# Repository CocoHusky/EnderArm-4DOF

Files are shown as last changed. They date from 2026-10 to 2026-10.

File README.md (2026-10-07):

# Ender 3 → 4-DOF Robot Arm

Convert a low-cost used Creality Ender 3 or Ender 3 Pro into a programmable 4-DOF robotic arm for learning robotics, kinematics, motion control, and non-Cartesian mechanisms.

<p align="center">
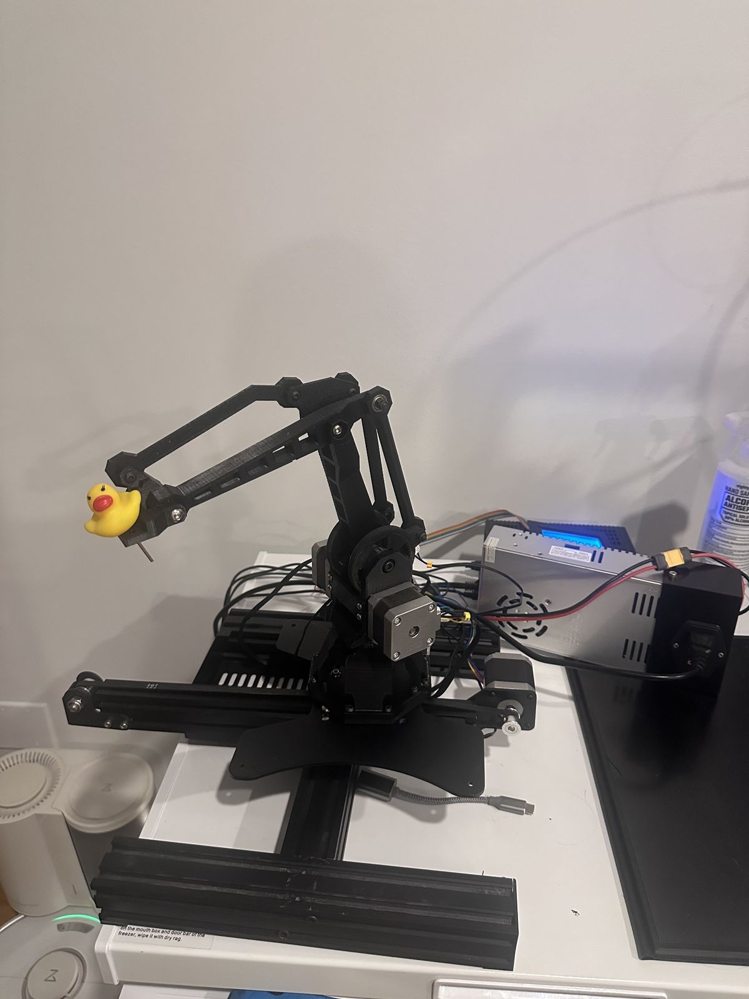
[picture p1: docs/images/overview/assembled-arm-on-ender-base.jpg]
EnderArm 4-DOF reference build mounted on the retained Ender 3 base
  
</p>

The project reuses the donor printer's frame components, stepper motors, power supply, wiring, endstops, controller board, and original linear Y-axis. The reference build was developed and tested from an Ender 3. An Ender 3 Pro can be used as well; board revisions and mounting details should always be verified before flashing firmware or assembling printed parts.

## Reference build

The photos below show the current working reference assembly and the major subsystems reused from the donor printer.

| Arm and linkage | Complete reference system |
| --- | --- |
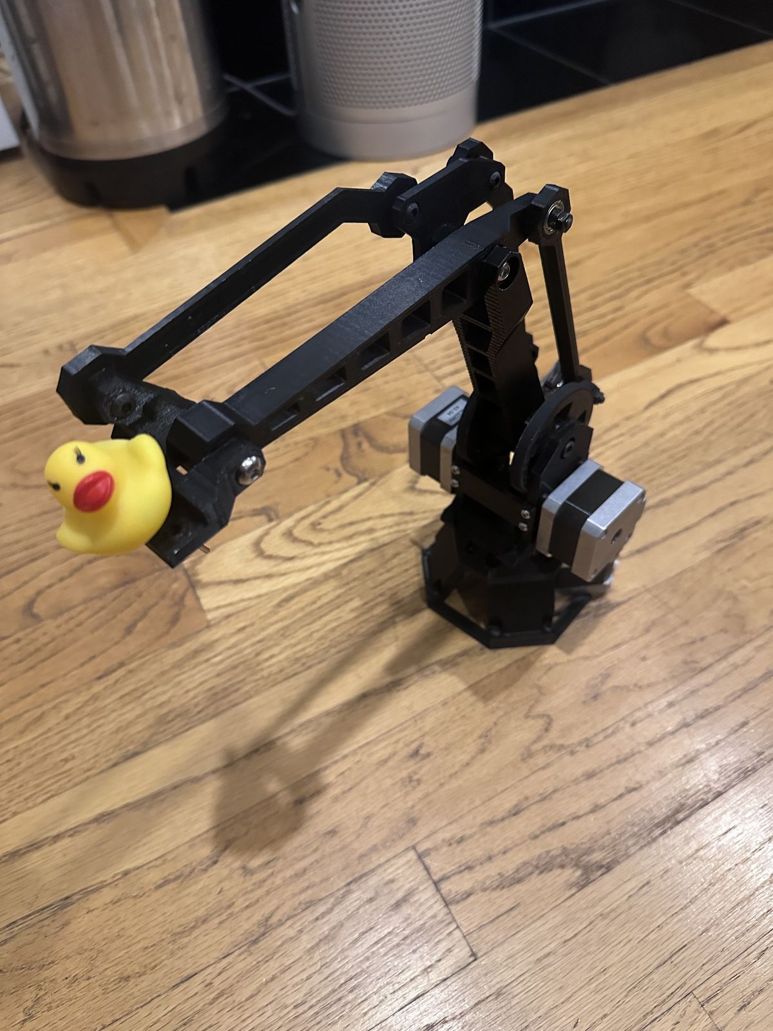
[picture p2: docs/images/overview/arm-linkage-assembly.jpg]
Standalone closed-linkage arm
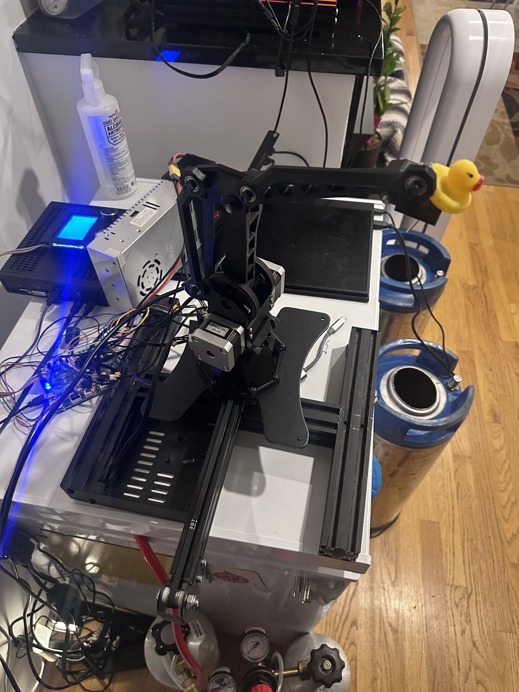
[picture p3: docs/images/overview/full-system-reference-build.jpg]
Complete EnderArm reference build
|  |  |
| **Base rotation and endstops** | **Controller and host wiring** |
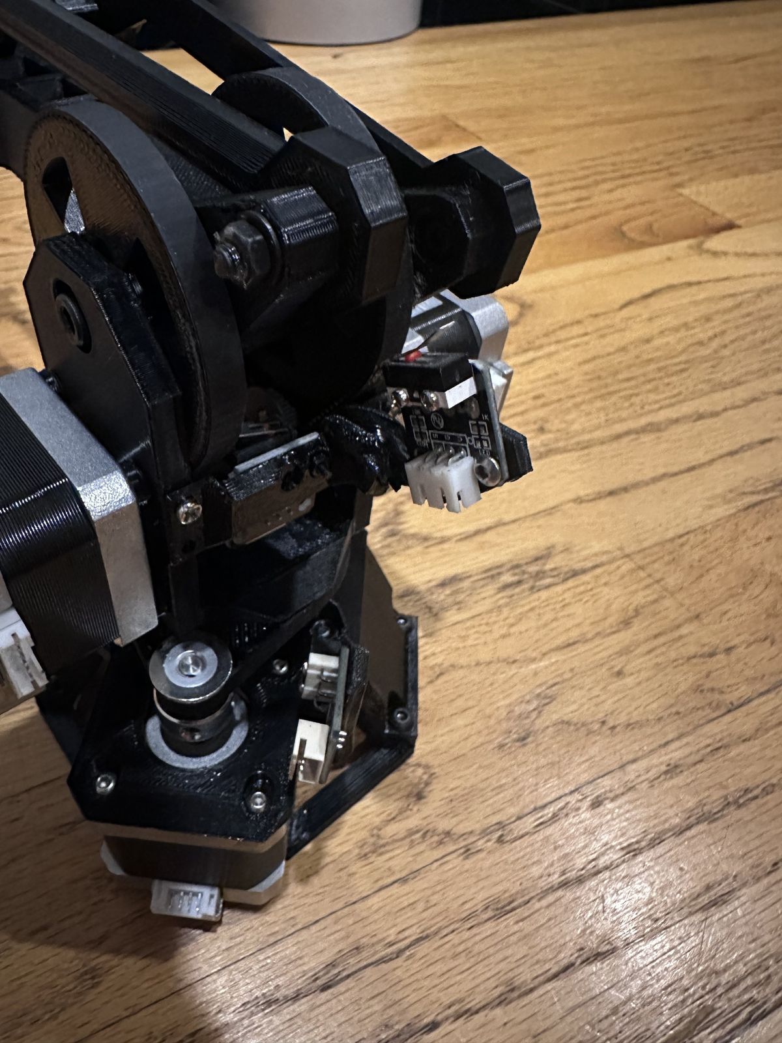
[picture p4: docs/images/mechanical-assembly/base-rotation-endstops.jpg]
Base rotation and endstop hardware
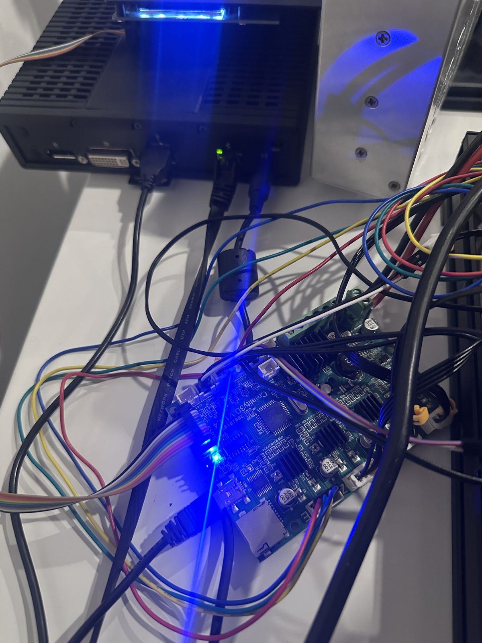
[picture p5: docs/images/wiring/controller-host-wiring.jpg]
Original Ender controller and host wiring
|  |  |

A detailed bearing and linkage close-up is available in [the mechanical assembly photos](docs/images/mechanical-assembly/linkage-bearing-detail.jpg).

## Current use: pouring beer

The current working robot is being used as a practical motion-control demo to **pour beers**. That use case exercises the same capabilities the project was built to study: repeatable homing, coordinated 4-axis motion, Cartesian targeting, smooth trajectories, and safe workspace limits.

## Why this project exists

A 3D printer is already a complete motion-control platform: stepper motors, drivers, power electronics, limit switches, belts, pulleys, a rigid frame, and a host-to-controller communication path. This project repurposes those parts into an articulated mechanism so the same hardware can be used to study:

- forward and inverse kinematics
- closed-linkage motion
- joint-space and Cartesian control
- homing and calibration
- motion planning
- workspace limits
- motor dynamics
- belt reduction
- coordinated multi-axis motion
- embedded motion control with Klipper

A used Ender 3 can often be found for roughly $30. The conversion is designed to reuse as much original hardware as possible.

## Four degrees of freedom

The arm uses four powered motions:

| DOF | Function | Donor hardware |
| --- | --- | --- |
| 1 | Linear base travel | Original Ender Y-axis carriage |
| 2 | Base rotation | Reused Ender stepper |
| 3 | Main arm joint | Reused Ender stepper, 20T-to-90T belt reduction |
| 4 | Crank/linkage joint | Reused Ender stepper, 20T-to-90T belt reduction |

The two arm-side motors drive a closed linkage rather than a conventional serial shoulder/elbow pair. The main arm is driven through the 120 mm A-C link and the second motor drives the 40 mm A-B crank. The linkage constrains the remaining arm geometry and keeps the tool structure oriented through the workspace.

## Control architecture

The reference control stack uses the original Ender controller board as the real-time motion controller running Klipper.

```text
Browser / control UI
        |
        v
Python arm controller + kinematics
        |
        v
Moonraker / Klipper host
        |
       USB
        |
        v
Original Ender controller board
        |
        v
4 stepper motors + endstops
```

The host can be any Raspberry Pi, single-board computer, mini PC, desktop, or laptop capable of running Debian/Linux, Klipper, Moonraker, and the control application.

The reference build also needed a **fourth endstop input** for the retained linear axis. On the reference 8-bit Creality board, an unused **bed-temperature / B-MOT thermistor input** was repurposed as a digital endstop input rather than adding another controller. The switch is read by Klipper as a pulled-up digital input; details are documented in the hardware/software setup.

**Minimum host requirement:** approximately **2 GB RAM and 2 GB available storage**. A dedicated host is not required if an existing Linux computer can be used.

## Additional hardware

The conversion is intended to keep the purchased hardware minimal. The reference build uses:

- GT2 timing belt, 200 mm long and 6 mm wide for the side-joint drives
- the donor X/Y stepper motors with their existing 20-tooth GT2 pulleys retained
- standard 686ZZ bearings (6 mm bore × 13 mm OD × 5 mm wide) where used by the linkage
- 6 mm precision steel balls used inside the printed bearing-shell assembly
- `686ZZ M5 Bearing Spacer.stl` adapts a standard 686ZZ for the original M5 Ender fastener while providing flange-like retention
- `Ender XY 20T Pulley Motor Spacer.stl` lets the donor X/Y steppers retain their already-installed 20T pulleys
- `6mm Ball Thrust Bearing Shell Top.stl` and `6mm Ball Thrust Bearing Shell Bottom.stl` use loose 6 mm steel balls instead of a purchased thrust bearing

The 6 mm loose balls and the 686ZZ bearings serve different functions: the loose balls run in the printed bearing shell, while the 686ZZ is used with the printed M5 bearing spacer. Exact quantities and part-by-part locations are maintained in the hardware documentation.

## Repository layout

```text
EnderArm-4DOF/
├── README.md
├── CONTRIBUTING.md
├── THIRD_PARTY.md
├── docs/
│   ├── README.md
│   ├── build/
│   ├── electronics/
│   ├── host/
│   ├── kinematics/
│   ├── calibration/
│   ├── troubleshooting/
│   └── images/
├── hardware/
│   ├── README.md
│   ├── bom/
│   ├── stl/
│   ├── step/
│   └── adapters/
├── software/
│   ├── README.md
│   ├── host/
│   ├── klipper/
│   └── tests/
└── config/
    ├── ender3/
    └── ender3-pro/
```

## Build path

1. Verify the donor printer and controller board.
2. Disassemble the X/Z gantry while retaining the Y-axis base.
3. Print the arm components and Ender-specific adapters.
4. Assemble the base rotation and closed-linkage arm.
5. Install belts, pulleys, bearings, and endstops.
6. Wire the four reused Ender steppers to the original controller.
7. Install Klipper and Moonraker on the host.
8. Install the EnderArm control software.
9. Home and calibrate each powered axis.
10. Measure the physical joint-zero offsets.
11. Validate the workspace boundary.
12. Test joint-space motion, Cartesian targets, and coordinated trajectories.

## Kinematics

The side-plane arm uses the following coordinate convention:

- origin A: the concentric side-drive pivot
- +Y: outward toward the tool
- +Z: upward
- +X: normal to the side plane
- qX: angle of the 120 mm A-C main arm
- qY: angle of the 40 mm A-B crank
- 0°: link points along +Z
- positive angle: rotation from +Z toward +Y

The main driven points are:

```text
B = (40 sin(qY), 40 cos(qY))
C = (120 sin(qX), 120 cos(qX))
```

Both side drives use a 20T motor pulley and 90T output pulley, giving a 4.5:1 reduction.

Detailed linkage geometry, forward kinematics, inverse kinematics, Cartesian-to-joint conversion, and motor-ratio math are documented in [`docs/kinematics/README.md`](docs/kinematics/README.md).

## Photos and build documentation

All build photography follows the capture plan in `docs/images/README.md`. Photos are organized by build stage so each image can be referenced directly from the corresponding assembly document.

## Third-party mechanical design

This conversion builds on an existing printable parallel-link robot-arm design. Upstream attribution and redistribution terms are documented in `THIRD_PARTY.md`.

Third-party files should only be committed to this repository when their license explicitly permits redistribution. Ender-specific adapters and modifications are maintained separately so the origin of each file remains clear.

## Project status

The mechanical conversion and arm-control workflow have been validated on the working Ender 3 reference build. Documentation, source CAD, printable files, host setup, Klipper configuration, and calibration procedures are being organized here as a reproducible build.

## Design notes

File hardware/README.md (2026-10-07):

# Hardware

This directory contains the mechanical files, Ender-specific conversion parts, and bill of materials for the Ender 3 / Ender 3 Pro to 4-DOF robot-arm conversion.

## Structure

- bom/ — donor hardware and additional parts to buy
- stl/ — arm printable files
- step/ — editable CAD exchange files
- adapters/ — Ender-specific conversion parts

Third-party printable files should retain their original attribution and license. Ender-specific parts are kept separately so it is clear which pieces belong to this conversion.

## Base arm design and assembly reference

The main arm geometry comes from the ToolKnox robotic-arm design. Use the upstream mechanical model and assembly sequence for the core printed arm parts:

- [ToolKnox robotic-arm project](https://github.com/ToolKnox/Robotic-Arm-Arduino-project)
- [Mechanical assembly guide](https://github.com/ToolKnox/Robotic-Arm-Arduino-project/blob/main/docs/assembly-guide.md)
- [Original printable model](https://www.printables.com/model/1439965-robotic-arm-arduino-project)

Follow those instructions for the **main structural arm assembly**. Then apply the Ender-specific substitutions documented below: retained Ender linear base, Ender motors/controller, printed bearing replacements, M5 bearing adapters, and motor spacers.

Do **not** follow the upstream Arduino/RAMPS electronics setup for this conversion; EnderArm reuses the Ender controller and Klipper.

## Print settings used for the conversion parts

The settings below apply to the **Ender-specific conversion parts in this repository**. For the main structural arm parts, follow the upstream ToolKnox print and assembly guidance unless intentionally changing the source design.

The Ender-specific adapter parts were dimensioned and fit-adjusted around the following print setup:

- **0.4 mm nozzle**
- **100% infill**
- **100% model scale**
- a dimensionally calibrated, high-quality FDM printer
- reference print quality comparable to a well-tuned Ender 3 Pro, Bambu Lab printer, or another printer with good dimensional accuracy

The bearing fits, shims, spacers, and motor spacing were adjusted for this printing condition. Print the conversion parts at 100% scale first.

Printer extrusion width, flow calibration, shrinkage, elephant foot, and hole compensation can still change the final fit. If a part is too tight or loose, correct printer calibration or local hole compensation rather than globally scaling the model.

## How the Ender conversion is assembled

The mechanical conversion keeps the useful motion hardware from the Ender and replaces the printer gantry with the articulated arm.

### 1. Retain the Ender linear base

Keep the original Ender Y-axis rail, carriage, belt drive, stepper, extrusion, and base frame.

This becomes the robot's **linear base axis**. The complete arm assembly rides on the original moving carriage.

### 2. Build the rotating arm base

The arm base mounts to the retained Ender carriage.

The source design uses a purchased thrust bearing at the rotating base. EnderArm replaces it with:

- [6mm Ball Thrust Bearing Shell Top.stl](adapters/6mm%20Ball%20Thrust%20Bearing%20Shell%20Top.stl)
- [6mm Ball Thrust Bearing Shell Bottom.stl](adapters/6mm%20Ball%20Thrust%20Bearing%20Shell%20Bottom.stl)
- loose **6 mm precision steel balls**

The two printed shells form the bearing race and the steel balls run between them.

### 3. Replace F624ZZ bearings with standard 624ZZ bearings

Where the source arm calls for F624ZZ flanged bearings, EnderArm uses:

- standard **624ZZ bearings**
- [624ZZ Flange Shim.stl](adapters/624ZZ%20Flange%20Shim.stl)

The shim provides the required flange interface while allowing inexpensive standard 624ZZ bearings to be used.

### 4. Replace F686ZZ / M6 interfaces with standard 686ZZ + original M5 hardware

The linkage uses standard **686ZZ bearings** together with:

- [686ZZ M5 Bearing Spacer.stl](adapters/686ZZ%20M5%20Bearing%20Spacer.stl)

The 686ZZ has a 6 mm bore. The printed spacer adapts the bearing to the original Ender M5 fastener and provides the locating surface needed by the linkage.

This lets the build reuse the Ender's M5 hardware instead of requiring the source design's M6 pivot arrangement or specialty flanged bearings.

### 5. Reuse the Ender X/Y motors with their 20T pulleys still installed

The donor X/Y stepper motors already have 20-tooth GT2 pulleys on their shafts.

Use:

- [Ender XY 20T Pulley Motor Spacer.stl](adapters/Ender%20XY%2020T%20Pulley%20Motor%20Spacer.stl)

The spacer moves each motor to the correct belt plane so the original pulley can stay installed.

The two side-linkage drives use the retained **20T motor pulley → 90T driven pulley** reduction.

This gives a 4.5:1 reduction between motor-shaft angle and linkage-output angle.

### 6. Install the closed-linkage arm

Assemble the source arm geometry around the two driven 90T side joints.

The two independently powered side joints are:

- **Main-arm drive** — 120 mm A→C link
- **Crank drive** — 40 mm A→B link

The remaining pivots are passive and are constrained by the closed linkage. See [docs/kinematics/README.md](../docs/kinematics/README.md) for the complete geometry and Cartesian-to-joint math.

### 7. Install the remaining rotary drive and belts

The build uses three 200 mm × 6 mm closed-loop GT2 belts for the rotary belt-driven joints.

Two 20T pulleys are reused directly from the donor X/Y motors. The additional 20T pulley can be purchased or printed:

- [GT2 20T pulley, 5 mm bore, optimized for FDM](https://www.printables.com/model/730635-gt2-20t-pully-5mm-bore-optimized-for-fdm)

### 8. Verify the mechanism before powered motion

Before connecting powered motion:

1. Move the retained linear carriage through its full travel by hand.
2. Rotate the base and confirm the printed loose-ball bearing moves smoothly.
3. Rotate both 90T linkage outputs by hand and verify that the linkage remains on the intended assembly branch.
4. Confirm that the 624ZZ flange shims stay seated and do not bind the bearings.
5. Confirm that the 686ZZ M5 spacers locate the bearings without clamping the rotating races.
6. Check that all GT2 belts track in one plane and do not rub printed parts.
7. Verify that cables can reach the full workspace without becoming tension members.

Do not proceed to high-speed motion until every axis moves freely by hand.

## Fourth endstop using the temperature-sensor input

The 4-DOF conversion needs one more limit-switch input than the original motion layout provides.

On the **reference 8-bit Creality V1.1.4-style controller**, the unused **bed thermistor / B-MOT temperature-sensor input** was repurposed as the fourth endstop input.

Reference wiring:

```text
B-MOT / PA6  ---- switch ---- GND
```

Klipper enables the MCU pull-up, so the normally-open switch pulls the input to ground when triggered. On the reference board this was verified in Klipper: the input changed from `open` to `TRIGGERED` when the switch was held.

Important: this means that connector is no longer being used as an analog temperature input. It is intentionally reconfigured as a digital switch input for the robot.

The exact MCU pin depends on the donor-controller revision. The **PA6 mapping is for the reference 8-bit board** and should not be copied to a different Creality board revision without checking its schematic/pin map.

## Ender-specific conversion parts

| Part | Qty | Purpose |
| --- | ---: | --- |
| [624ZZ Flange Shim.stl](adapters/624ZZ%20Flange%20Shim.stl) | 6 | Allows standard 624ZZ bearings to replace F624ZZ flanged bearings |
| [6mm Ball Thrust Bearing Shell Top.stl](adapters/6mm%20Ball%20Thrust%20Bearing%20Shell%20Top.stl) | 1 | Upper race for the printed loose-ball thrust bearing |
| [6mm Ball Thrust Bearing Shell Bottom.stl](adapters/6mm%20Ball%20Thrust%20Bearing%20Shell%20Bottom.stl) | 1 | Lower race for the printed loose-ball thrust bearing |
| [686ZZ M5 Bearing Spacer.stl](adapters/686ZZ%20M5%20Bearing%20Spacer.stl) | 12 | Adapts standard 686ZZ bearings to the original Ender M5 pivot hardware |
| [Ender XY 20T Pulley Motor Spacer.stl](adapters/Ender%20XY%2020T%20Pulley%20Motor%20Spacer.stl) | 2 | Aligns donor X/Y motors while retaining their installed 20T pulleys |

For quantities of bearings, belts, fasteners, and donor parts, see the [hardware BOM](bom/).

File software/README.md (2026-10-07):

# Software

EnderArm splits high-level robot geometry from deterministic step timing.

```text
Browser UI
    |
    v
robot_mapper_klipper.py
    |
    +--> kinematics.py
    |
    v
Moonraker
    |
    v
Klipper
    |
   USB
    |
    v
original Ender controller board
```

## Host requirements

A Dell Wyse is **not required**. Use a Raspberry Pi, mini PC, old laptop, thin client, or other Debian/Linux machine.

Minimum practical target:

- **2 GB RAM**
- **2 GB available storage**
- Python 3
- USB connection to the Ender controller
- network access if the UI is opened from another device

The reference build used a used Dell Wyse only because it was cheaper than Raspberry Pi hardware at the time.

## Source files

| File | Purpose |
| --- | --- |
| [`host/kinematics.py`](host/kinematics.py) | Exact closed-linkage geometry, forward kinematics, inverse kinematics, coordinate transforms, motor/output conversion |
| [`host/robot_mapper_klipper.py`](host/robot_mapper_klipper.py) | Browser UI, workspace model, boundary checking, Moonraker communication, joint/tool commands |
| [`klipper/arm_robot.py`](klipper/arm_robot.py) | Klipper extra module for native robot-arm homing and coordinated A/B/C arm axes |
| [`tests/test_kinematics.py`](tests/test_kinematics.py) | Geometry and kinematics regression tests |

## Install Debian/Linux packages

```bash
sudo apt update
sudo apt install -y git python3
```

Install Klipper and Moonraker using their normal Linux installation process.

## Clone EnderArm

```bash
cd ~
git clone https://github.com/CocoHusky/EnderArm-4DOF.git
cd EnderArm-4DOF
```

## Install the Klipper arm module

For a normal Klipper checkout at `~/klipper`:

```bash
cp software/klipper/arm_robot.py ~/klipper/klippy/extras/arm_robot.py
```

Add this section to `printer.cfg`:

```ini
[arm_robot]
```

The current module expects these exact Klipper object names:

```ini
[manual_stepper joint_x]
# qX: main A -> C drive

[manual_stepper joint_y]
# qY: A -> B crank drive

[manual_stepper joint_z]
# base-yaw drive
```

Use the **actual step/dir/enable/endstop pins for the donor controller board**. Ender 3 and Ender 3 Pro boards exist in multiple revisions, so pin assignments from another board should not be copied blindly.

The retained Ender rail is the fourth powered coordinate. Calibrate that rail in millimetres using the real donor belt, pulley, motor, and travel.

## Start the web controller

```bash
python3 software/host/robot_mapper_klipper.py
```

The checked-in controller uses:

```text
Moonraker: http://127.0.0.1:7125
Web UI:    0.0.0.0:8765
```

Open it from another machine at:

```text
http://<linux-host-ip>:8765
```

There is no required fixed IP address.

## Inverse-kinematics path

For an arm-local Cartesian command:

```text
desired tool Y,Z
        |
        v
inverse_side()
        |
        v
qX, qY 90T output angles
        |
        v
home-offset / direction calibration
        |
        v
Klipper coordinated motion
```

`inverse_side()` uses the exact closed-linkage geometry, not a serial two-link shoulder/elbow approximation. It uses a finite-difference Jacobian with a 0.01° step, converges below 0.01 mm tool error, allows up to 80 iterations, and rejects near-singular solves when `|det(J)| < 1e-8`.

See [the full kinematics derivation](../docs/kinematics/README.md).

## Run the regression tests

```bash
cd software/host
python3 -m unittest -v ../tests/test_kinematics.py
```

The development source currently passes the geometry/kinematics regression suite before publication.

## First-power checks

Before normal operation:

1. confirm Klipper reaches `ready`
2. verify every endstop changes state correctly
3. verify motor directions at low speed
4. home one mechanism at a time
5. confirm the linkage remains on the physical Assembly-1 branch
6. verify the measured X/Y joint-space boundary
7. calibrate physical home offsets and linear-rail travel
8. check cable clearance over the full workspace

## Fourth endstop: repurposing a thermistor input

The retained linear axis requires a fourth homing/limit input.

On the reference 8-bit Creality V1.1.4-style board, the unused bed-temperature input was repurposed as a digital endstop input:

```text
B-MOT / MCU PA6 -> normally-open switch -> GND
```

The Klipper-side change is to use that MCU pin as an endstop rather than as a thermistor ADC input. For the reference board, the endstop declaration uses the internal pull-up:

```ini
# Reference 8-bit Creality board only
endstop_pin: ^PA6
```

The leading `^` enables the pull-up. With the switch open, the input remains high; closing the switch pulls PA6 to ground and Klipper reports it as triggered.

This was verified on the reference controller by watching the switch state change from `open` to `TRIGGERED`.

Do not configure the same PA6 pin simultaneously as a temperature sensor and an endstop. The temperature-sensor definition for that connector must be removed/disabled when the input is repurposed.

Different Ender controller revisions use different MCU pins, so the pin value above is specific to the reference 8-bit board.

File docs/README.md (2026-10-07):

# Documentation

The documentation is organized in the same order a new builder should follow.

## Build sequence

- `build/` — donor printer, disassembly, printed parts, and mechanical assembly
- `electronics/` — controller board, motors, endstops, power, and wiring
- `host/` — Raspberry Pi or other Debian/Linux host setup; minimum 2 GB RAM and 2 GB available storage
- `kinematics/` — linkage geometry, coordinate frames, forward and inverse kinematics
- `calibration/` — homing, zero offsets, workspace measurement, and validation
- `troubleshooting/` — mechanical, wiring, Klipper, and motion-control problems
- `images/` — required build photographs, screenshots, and validation videos

The build guide should be usable from start to finish without requiring knowledge of the development history of the project.

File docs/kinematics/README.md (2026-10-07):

# Kinematics and Cartesian-to-Motor Math

This document defines the mathematical model used by EnderArm. It intentionally separates the robot geometry from the Ender controller connector names.

All lengths are in millimetres. Public joint angles are in degrees unless otherwise noted.

## Joint map

The drawing below is generated from the same dimensions used by the kinematic model. Its illustrative pose uses `qX=+22°` and `qY=-90°` only to make the mechanism easy to read: **A→B and A→G are visibly separate**, and **F→C→H is shown as the single straight rigid member defined by the solver**. Those display angles are not home or calibration-zero values.

Exact EnderArm closed-linkage kinematics

The four powered robot coordinates are:

- `s` — linear base travel; translates the complete arm on the retained Ender rail
- `ψ` — base yaw; rotates the complete Y-Z side linkage about vertical Z
- `qX` — main-arm joint; the 90T output that directly drives A→C
- `qY` — crank joint; the 90T output that directly drives A→B

The diagram is reproducible from [`generate_kinematics_diagram.py`](generate_kinematics_diagram.py). The generator validates the fixed member lengths and F-C-H collinearity before writing the SVG.

## 1. Actuated coordinates

EnderArm has four powered coordinates:

| Symbol | Name | Meaning |
| --- | --- | --- |
| `s` | Linear base travel | Translation of the complete arm along the retained Ender linear rail |
| `ψ` | Base yaw | Rotation of the complete arm about the vertical axis |
| `qX` | Main-arm joint | Absolute angle of the 120 mm A→C driven link |
| `qY` | Crank joint | Absolute angle of the 40 mm A→B driven crank |

`qX` and `qY` are angles of the 90-tooth driven outputs, not motor-shaft angles.

The remaining labelled pivots are passive linkage points. They are determined by `qX` and `qY`.

## 2. Side-plane coordinate frame

The closed linkage is solved in the Y-Z plane.

```text
A = (Y=0, Z=0)
+Y = outward from the base toward the tool
+Z = upward

q = 0°   -> link points along +Z
q = +90° -> link points along +Y
```

Angles are therefore measured from +Z toward +Y.

The common drive origin is point A.

## 3. Link dimensions

The current physical model uses:

| Link | Length |
| --- | ---: |
| A-B | 40 mm |
| A-C | 120 mm |
| B-F | 120 mm |
| C-F | 40 mm |
| C-H | 120 mm |
| C-E / A-G | 32 mm |
| D-E | 45 mm |
| C-D / H-I | 25 mm |
| G-E / D-I | 120 mm |
| H-T | 27 mm |

The fixed support vector is

```text
G = (-26.933333, 17.279918)
```

in side-plane `(Y,Z)` coordinates.

## 4. Independent driven pivots

Let

```text
a = AB = 40
c = AC = 120
```

The crank tip B is

```text
B_y = a sin(qY)
B_z = a cos(qY)
```

or

```text
B(qY) = [40 sin(qY), 40 cos(qY)]
```

The main-arm pivot C is

```text
C_y = c sin(qX)
C_z = c cos(qX)
```

or

```text
C(qX) = [120 sin(qX), 120 cos(qX)]
```

These are the only two independent coordinates in the side linkage.

## 5. Solving the closed linkage

Point F is passive. It must simultaneously satisfy

```text
|F - B| = BF = 120
|F - C| = CF = 40
```

Therefore F is the intersection of two circles.

Define

```text
d = C - B
D = ||d||
e = d / D
```

where `e` is the unit vector from B toward C.

The distance from B to the projection of F onto the B-C line is

```text
u = (BF² - CF² + D²) / (2D)
```

The perpendicular distance from that line to F is

```text
h = sqrt(BF² - u²)
```

A perpendicular unit vector in the Y-Z plane is

```text
e_perp = [-e_z, e_y]
```

The two mathematical solutions are therefore

```text
F1 = B + u e + h e_perp
F2 = B + u e - h e_perp
```

Only one corresponds to the physical assembled arm. EnderArm uses the physical Assembly-1 branch.

If the two circles do not intersect, that pair of `qX,qY` angles is not physically reachable.

## 6. Remaining passive pivots

F, C, and H are collinear. Because

```text
CF = 40
CH = 120
```

the vector from C to H is three times the vector from F to C:

```text
H = C + (CH / CF)(C - F)
H = C + 3(C - F)
```

The lower parallelogram gives

```text
E = C + G
```

The triplate gives

```text
D = E + [45, 0]
```

The upper parallelogram gives

```text
I = H + (D - C)
```

The tool point is

```text
T = H + [27, 0]
```

Thus the complete side-plane forward-kinematics function is

```text
T = f(qX, qY)
```

The tool coordinates `T_y,T_z` are fully determined by the two driven 90T joint angles.

## 7. Forward kinematics

The complete side-plane calculation is:

```text
qX, qY
  ↓
B(qY), C(qX)
  ↓
circle intersection -> F
  ↓
H = C + 3(C-F)
  ↓
T = H + [27,0]
  ↓
(T_y, T_z)
```

This is why EnderArm must not be modeled as an ordinary serial two-link shoulder/elbow mechanism.

## 8. Side-plane inverse kinematics

Given a desired tool position

```text
T* = [Y*, Z*]
```

we need to find

```text
q = [qX, qY]^T
```

such that

```text
f(q) = T*
```

There is no simple serial-arm elbow equation because the tool position is produced by the complete closed linkage.

The reference controller uses a Newton/Jacobian solve.

Define the error

```text
e(q) = f(q) - T*
```

or

```text
e = [
    T_y(qX,qY) - Y*
    T_z(qX,qY) - Z*
]
```

The Jacobian is

```text
J = [
    ∂T_y/∂qX   ∂T_y/∂qY
    ∂T_z/∂qX   ∂T_z/∂qY
]
```

The implementation estimates the derivatives numerically with

```text
ε = 0.01°
```

For example,

```text
∂T_y/∂qX ≈ [T_y(qX+ε,qY) - T_y(qX,qY)] / ε
∂T_z/∂qX ≈ [T_z(qX+ε,qY) - T_z(qX,qY)] / ε
```

and equivalently for `qY`.

The Newton update is

```text
q_next = q - J⁻¹ e
```

For a 2×2 Jacobian

```text
J = [a b
     c d]
```

with

```text
det(J) = ad - bc
```

the correction used by the controller is

```text
ΔqX = ( d e_y - b e_z) / det(J)
ΔqY = (-c e_y + a e_z) / det(J)

qX <- qX - ΔqX
qY <- qY - ΔqY
```

The current implementation:

- starts from the current physical joint angles
- remains on Assembly 1
- stops when tool-position error is less than 0.01 mm
- allows up to 80 iterations
- rejects the solve when `|det(J)| < 1e-8`, because the linkage is near a singularity

Using the current pose as the seed is important. The closed linkage has multiple mathematical branches, and a distant arbitrary seed can converge to the wrong assembly.

## 9. Joint coordinates and physical home

Geometric zero and physical home are different.

Geometric zero is defined by

```text
qX = 0° -> A-C points along +Z
qY = 0° -> A-B points along +Z
```

After homing, the controller maps its measured joint coordinates to geometric angles with

```text
qX = qX_home + dirX (x - x_home)
qY = qY_home + dirY (y - y_home)
```

where

- `x,y` are the measured 90T output-joint coordinates
- `x_home,y_home` are the post-home reference values
- `dirX,dirY` account for motor/wiring direction
- `qX_home,qY_home` are physical calibration offsets

The current reference values in the development model are

```text
qX_home = -70°
qY_home = -104°
```

These are calibration values for the reference arm, not universal geometric constants.

## 10. 90T output angle to motor-shaft angle

Both side drives use

```text
20T motor pulley -> 90T output pulley
```

Therefore

```text
q_output = θ_motor (20 / 90)
```

and

```text
θ_motor = q_output (90 / 20)
θ_motor = 4.5 q_output
```

For commanded changes,

```text
Δθ_motor = 4.5 Δq_output
```

Examples:

| Output-joint motion | Motor-shaft motion |
| ---: | ---: |
| 1° | 4.5° |
| 5° | 22.5° |
| 10° | 45° |
| 20° | 90° |

Stepper pulse generation should be left to Klipper using the configured motor/driver parameters rather than hard-coding a microstep count into the kinematic model.

## 11. Side-plane Cartesian command to the two arm motors

The currently implemented Cartesian move performs this sequence:

```text
desired tool Y,Z
       ↓
inverse_side(Y,Z,current qX,current qY)
       ↓
desired qX,qY
       ↓
apply physical-home offsets and direction
       ↓
desired 90T output coordinates
       ↓
Klipper coordinated motion
       ↓
20T motor pulleys drive the 90T outputs
```

In equation form,

```text
(Y*, Z*)
    -> IK
(qX*, qY*)
    -> calibration transform
(x*, y*)
    -> motion planner
motor motion
```

## 12. Extending the side-plane model to world XYZ

Base yaw rotates the side-plane radial coordinate into world X-Y.

For a side-plane tool solution

```text
T_side = [r, z]
```

and base yaw `ψ`,

```text
X = r sin(ψ)
Y = r cos(ψ)
Z = z
```

Therefore, for a world target relative to the yaw-axis origin,

```text
r = sqrt(X² + Y²)
ψ = atan2(X, Y)
z = Z
```

The side-linkage inverse problem then becomes

```text
(qX,qY) = inverse_side(r,Z)
```

and the three rotary coordinates are

```text
ψ, qX, qY
```

## 13. Adding the linear base coordinate

The retained Ender rail translates the complete yaw axis.

Let

```text
s = linear-axis position
l_hat = unit vector of the physical rail in the chosen world frame
P0 = yaw-axis origin when s = 0
```

Then the moving base origin is

```text
P_base(s) = P0 + s l_hat
```

For a requested world tool point `P*`,

```text
p = P* - P_base(s)
```

Then

```text
r = sqrt(p_x² + p_y²)
ψ = atan2(p_x, p_y)
(qX,qY) = inverse_side(r,p_z)
```

This gives

```text
P* + chosen s
    ->
p relative to moving base
    ->
ψ,r,z
    ->
qX,qY
    ->
four actuator coordinates [s,ψ,qX,qY]
```

A position-only XYZ target contains three constraints while the robot has four actuated coordinates. Therefore `s` is a redundant degree of freedom for a pure XYZ command.

A controller must choose `s` using an additional rule, for example:

- keep the current linear position when the target is reachable
- choose `s` that maximizes distance from the side-linkage workspace boundary
- minimize total joint motion
- minimize motor effort
- prefer the center of linear travel

Once `s` is chosen, the remaining inverse mapping is deterministic for the selected physical linkage branch.

## 14. Complete mathematical control chain

```text
Desired world tool point P*
        +
linear-axis policy
        ↓
choose s
        ↓
P_base(s) = P0 + s l_hat
        ↓
p = P* - P_base(s)
        ↓
ψ = atan2(p_x,p_y)
r = sqrt(p_x²+p_y²)
z = p_z
        ↓
closed-linkage IK
        ↓
qX, qY
        ↓
home-offset / direction calibration
        ↓
90T output coordinates
        ↓
20T:90T ratio
        ↓
motor-shaft motion
        ↓
Klipper trajectory generation
```

The kinematic layer should produce physical actuator coordinates. Klipper should remain responsible for converting those coordinates into timed step pulses.

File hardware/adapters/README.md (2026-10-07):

# Ender-specific adapters

These parts were created for the EnderArm conversion so the build can reuse original Ender hardware and lower-cost commodity bearings.

## Print settings

The adapter geometry and fit were tuned around:

- **0.4 mm nozzle**
- **100% infill**
- **100% model scale**
- a dimensionally calibrated FDM printer with good dimensional accuracy

A well-tuned Ender 3 Pro, Bambu Lab printer, or another high-quality printer should be an appropriate starting point.

The bearing seats, shims, M5 interface, and motor spacing include fit adjustments based on these settings. Printer calibration still matters: flow, shrinkage, elephant foot, and hole compensation can change a nominally identical print.

## 624ZZ flange shim

[624ZZ Flange Shim.stl](624ZZ%20Flange%20Shim.stl) allows a standard 624ZZ bearing to be used where the source design calls for an F624ZZ flanged bearing.

Use one shim with each 624ZZ bearing.

## 6 mm ball thrust-bearing shell

[6mm Ball Thrust Bearing Shell Top.stl](6mm%20Ball%20Thrust%20Bearing%20Shell%20Top.stl) and [6mm Ball Thrust Bearing Shell Bottom.stl](6mm%20Ball%20Thrust%20Bearing%20Shell%20Bottom.stl) form the printed thrust-bearing race.

Fill the race with 6 mm precision steel balls during assembly. This replaces the purchased thrust-bearing assembly used by the source robot design.

## 686ZZ M5 bearing spacer

[686ZZ M5 Bearing Spacer.stl](686ZZ%20M5%20Bearing%20Spacer.stl) is used with a standard 686ZZ bearing.

The 686ZZ has a 6 mm bore. The spacer creates the M5-compatible pivot interface required to reuse the original Ender fastener and provides the locating surface needed by the linkage.

## Ender XY 20T pulley motor spacer

[Ender XY 20T Pulley Motor Spacer.stl](Ender%20XY%2020T%20Pulley%20Motor%20Spacer.stl) positions the donor X/Y stepper motors correctly for the arm belt drives.

It is specifically designed so the original 20-tooth GT2 pulley can remain installed on the motor shaft.

## Files

- 624ZZ Flange Shim.stl
- 6mm Ball Thrust Bearing Shell Top.stl
- 6mm Ball Thrust Bearing Shell Bottom.stl
- 686ZZ M5 Bearing Spacer.stl
- Ender XY 20T Pulley Motor Spacer.stl

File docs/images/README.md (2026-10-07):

# Build photography

Use this directory for the photographs and screenshots referenced by the build documentation.

Photographs should be clear engineering documentation rather than decorative images. Use a clean background, even lighting, and enough resolution to show hardware details. Keep the same arm orientation between related photos when possible.

## Current reference photos

These cleaned reference-build photographs are already included in the repository:

| File | Use |
| --- | --- |
| `overview/assembled-arm-on-ender-base.jpg` | Arm mounted on the retained Ender base |
| `overview/arm-linkage-assembly.jpg` | Standalone closed-linkage arm assembly |
| `overview/full-system-reference-build.jpg` | Complete working system and retained linear axis |
| `mechanical-assembly/linkage-bearing-detail.jpg` | Linkage bearing and fastener detail |
| `mechanical-assembly/base-rotation-endstops.jpg` | Base rotation and endstop arrangement |
| `wiring/controller-host-wiring.jpg` | Original Ender controller and host connection |

The repository copies are re-encoded JPEGs with camera metadata removed.

## File format

- Photos: JPG
- Diagrams and screenshots: PNG or SVG
- Video clips: MP4
- Short motion previews: GIF only when a static image cannot explain the action
- Use lowercase filenames with hyphens
- Do not include camera-generated names such as `IMG_4821.jpg`

## overview

These are the main project images.

| File | Shot |
| --- | --- |
| `overview/hero-assembled-arm.jpg` | Finished arm, front three-quarter view, neutral pose |
| `overview/hero-side-view.jpg` | Finished arm, exact side view showing the closed linkage |
| `overview/ender3-before.jpg` | Complete donor Ender 3 before disassembly |
| `overview/ender3-to-arm.jpg` | Donor printer and finished arm shown together or as a clean before/after pair |
| `overview/arm-in-motion.jpg` | Arm in a useful extended pose |
| `overview/workspace-poses.jpg` | Three or more representative poses showing the available workspace |

The main README should use `hero-assembled-arm.jpg` once it exists.

## donor-printer

Document exactly what the builder starts with.

| File | Shot |
| --- | --- |
| `donor-printer/ender3-front.jpg` | Full Ender 3 from the front |
| `donor-printer/ender3-pro-front.jpg` | Ender 3 Pro example, if available |
| `donor-printer/controller-board.jpg` | Controller board with board revision readable |
| `donor-printer/controller-connectors.jpg` | Motor, endstop, power, and USB connectors visible |
| `donor-printer/donor-motors.jpg` | Four donor stepper motors laid out and labeled by original axis |
| `donor-printer/reused-hardware.jpg` | Screws, T-nuts, endstops, belts, pulleys, wiring, and other reused hardware laid out |
| `donor-printer/y-axis-base.jpg` | Original Y-axis base assembly that remains in the robot |

## disassembly

Take each photo before removing the next major assembly.

| File | Shot |
| --- | --- |
| `disassembly/stock-printer.jpg` | Printer before disassembly |
| `disassembly/remove-top-crossbar.jpg` | Top crossbar fasteners and removal |
| `disassembly/remove-x-gantry.jpg` | X gantry before and during removal |
| `disassembly/remove-z-extrusions.jpg` | Vertical extrusions and mounting screws |
| `disassembly/remove-unused-components.jpg` | Extruder/hotend and printer-only components being removed |
| `disassembly/retained-base.jpg` | Final retained Ender base with Y-axis carriage |
| `disassembly/retained-parts-layout.jpg` | Every donor part used by the arm laid out and labeled |
| `disassembly/unused-parts-layout.jpg` | Major donor parts not required for the conversion |

## printed-parts

These images let a builder identify every printed part before assembly.

| File | Shot |
| --- | --- |
| `printed-parts/all-parts-labeled.jpg` | Complete printed-parts set with labels matching STL filenames |
| `printed-parts/print-orientation-arm-parts.jpg` | Recommended print orientation for the major linkage parts |
| `printed-parts/print-orientation-adapters.jpg` | Recommended orientation for the Ender-specific adapters |
| `printed-parts/m5-bearing-spacer.jpg` | M5-to-bearing spacer alone, close and in focus |
| `printed-parts/m5-bearing-spacer-installed.jpg` | Spacer installed in the bearing interface with an original M5 screw |
| `printed-parts/printed-20t-pulley.jpg` | Optional printed 20T pulley, if used |
| `printed-parts/90t-output-pulley.jpg` | 90T output pulley/gear used by the side joints |

## hardware

Show every non-printed purchased component at a scale that makes identification easy.

| File | Shot |
| --- | --- |
| `hardware/gt2-belt.jpg` | GT2 belt with width and length reference |
| `hardware/20t-pulley.jpg` | 20T GT2 motor pulley |
| `hardware/686zz-bearing.jpg` | 686ZZ bearing with ruler/caliper or marked dimensions |
| `hardware/6mm-steel-balls.jpg` | 6 mm precision steel balls with scale reference |
| `hardware/additional-hardware-layout.jpg` | Complete purchased hardware set for one arm |

Keep the 686ZZ bearing and 6 mm steel balls as separate documented parts. The 6 mm balls belong in the printed bearing-shell assembly; the 686ZZ uses the printed M5 bearing spacer.

## mechanical-assembly

This is the most important photo set. Photograph every joint before it is hidden by the next part.

| File | Shot |
| --- | --- |
| `mechanical-assembly/linear-base.jpg` | Retained Ender Y-axis used as the linear DOF |
| `mechanical-assembly/base-rotation.jpg` | Base rotation motor, shaft/pulley, and rotating structure |
| `mechanical-assembly/side-motor-mounts.jpg` | Two side-plane motors mounted |
| `mechanical-assembly/20t-to-90t-drive.jpg` | 20T motor pulley, GT2 belt, and 90T driven pulley in one shot |
| `mechanical-assembly/main-arm-ac.jpg` | 120 mm A-C main driven arm installed |
| `mechanical-assembly/crank-ab.jpg` | 40 mm A-B crank installed |
| `mechanical-assembly/lower-linkage.jpg` | B-F/C-F lower linkage assembled |
| `mechanical-assembly/parallelogram-linkage.jpg` | Parallel-link mechanism from the side |
| `mechanical-assembly/wrist-linkage.jpg` | H-I-T tool-side linkage |
| `mechanical-assembly/bearing-stack.jpg` | Bearing, spacer, screw, printed part, and washer stack in assembly order |
| `mechanical-assembly/m5-adapter-detail.jpg` | Close-up proving the original M5 screw works with the adapter |
| `mechanical-assembly/belt-routing.jpg` | Complete belt routing for both side drives |
| `mechanical-assembly/belt-tension.jpg` | Correct belt tension and adjustment point |
| `mechanical-assembly/endstops.jpg` | Endstop locations and trigger surfaces |
| `mechanical-assembly/complete-side-view.jpg` | Finished mechanical arm in exact side view |
| `mechanical-assembly/complete-front-view.jpg` | Finished arm from the front |
| `mechanical-assembly/complete-rear-view.jpg` | Finished arm from the rear, showing wiring path |

For the exact side-view photo, position the camera normal to the linkage plane. This image will also be used to explain the kinematic points A through T.

## wiring

The reader should be able to reproduce the wiring without guessing.

| File | Shot |
| --- | --- |
| `wiring/controller-labeled.jpg` | Controller board with each used connector labeled |
| `wiring/motor-x-connection.jpg` | First linkage motor connection |
| `wiring/motor-y-connection.jpg` | Second linkage motor connection |
| `wiring/base-rotation-connection.jpg` | Base-rotation motor connection |
| `wiring/linear-axis-connection.jpg` | Retained linear-axis motor connection |
| `wiring/endstop-connections.jpg` | All endstop connections |
| `wiring/power-input.jpg` | PSU-to-controller power connection |
| `wiring/usb-host-connection.jpg` | USB connection between host and Ender controller |
| `wiring/full-wiring-overview.jpg` | Entire electrical system in one view |
| `wiring/cable-management.jpg` | Final cable routing through full arm travel |

## host

Document the reference host without making it mandatory.

| File | Shot |
| --- | --- |
| `host/dell-wyse-reference.jpg` | Dell Wyse reference host |
| `host/dell-wyse-usb-network.jpg` | USB, Ethernet, and power connections |
| `host/raspberry-pi-example.jpg` | Optional Raspberry Pi host if one is tested |
| `host/laptop-usb-example.jpg` | Computer-hosted setup over USB |

## software

Use screenshots rather than camera photos.

| File | Shot |
| --- | --- |
| `software/klipper-ready.png` | Klipper/Moonraker showing the controller ready |
| `software/control-ui-home.png` | Main arm-control page after homing |
| `software/live-arm-view.png` | Live kinematic arm visualization |
| `software/joint-controls.png` | Joint-space controls |
| `software/cartesian-target.png` | Cartesian target controls |
| `software/workspace-boundary.png` | Measured/fitted workspace boundary |
| `software/click-to-move.png` | Click-to-move interaction |
| `software/dance-motion.png` | Dance/trajectory controls |
| `software/stop-control.png` | STOP control and motion status |

Do not include IP addresses, usernames, API tokens, Wi-Fi credentials, SSH keys, or other private information in screenshots.

## calibration

These images connect the equations to the physical machine.

| File | Shot |
| --- | --- |
| `calibration/home-pose-side.jpg` | Physical home pose from exact side view |
| `calibration/pivot-labels.jpg` | Same side view annotated A, B, C, D, E, F, G, H, I, T |
| `calibration/ac-120mm.jpg` | A-C link measurement |
| `calibration/ab-40mm.jpg` | A-B crank measurement |
| `calibration/tool-offset.jpg` | H-T tool offset measurement |
| `calibration/90t-zero-reference.jpg` | Physical zero/index reference on the 90T output |
| `calibration/linear-axis-zero.jpg` | Linear-axis home/zero point |
| `calibration/base-rotation-zero.jpg` | Base-rotation home/zero point |
| `calibration/workspace-min.jpg` | One measured workspace boundary pose |
| `calibration/workspace-max.jpg` | Opposite/extreme workspace boundary pose |

When showing a dimension, place a ruler or caliper in the same plane as the measured feature to minimize perspective error.

## validation

These are proof-of-operation images and videos.

| File | Shot |
| --- | --- |
| `validation/home-complete.jpg` | Arm successfully homed |
| `validation/linear-min.jpg` | Minimum linear travel |
| `validation/linear-max.jpg` | Maximum linear travel |
| `validation/base-min.jpg` | Base-rotation minimum |
| `validation/base-max.jpg` | Base-rotation maximum |
| `validation/workspace-extreme-1.jpg` | Arm at one validated linkage boundary |
| `validation/workspace-extreme-2.jpg` | Arm at another validated linkage boundary |
| `validation/cartesian-target.jpg` | Physical tool positioned at a commanded Cartesian target |
| `validation/dance.mp4` | Continuous coordinated motion using all four DOFs |
| `validation/click-to-move.mp4` | UI target selection followed by physical arm motion |

## Minimum photo set for the first public release

If only one photography session is available, capture these first:

1. `overview/hero-assembled-arm.jpg`
2. `overview/ender3-before.jpg`
3. `disassembly/retained-base.jpg`
4. `printed-parts/all-parts-labeled.jpg`
5. `printed-parts/m5-bearing-spacer-installed.jpg`
6. `hardware/additional-hardware-layout.jpg`
7. `mechanical-assembly/20t-to-90t-drive.jpg`
8. `mechanical-assembly/bearing-stack.jpg`
9. `mechanical-assembly/m5-adapter-detail.jpg`
10. `mechanical-assembly/complete-side-view.jpg`
11. `wiring/controller-labeled.jpg`
12. `wiring/full-wiring-overview.jpg`
13. `calibration/pivot-labels.jpg`
14. `calibration/90t-zero-reference.jpg`
15. `validation/dance.mp4`

That set is enough to make the main README, mechanical assembly guide, wiring guide, kinematics guide, and calibration guide visually complete.

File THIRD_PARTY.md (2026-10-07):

# Third-party sources

EnderArm combines original Ender-specific conversion work with a printable parallel-link robot-arm mechanism derived from earlier open designs.

## Mechanical arm source

The reference mechanical design and BOM used for this conversion are from [ToolKnox/Robotic-Arm-Arduino-project](https://github.com/ToolKnox/Robotic-Arm-Arduino-project), with the corresponding mechanical project hosted on Printables. Redistribution terms for unchanged upstream STL or CAD files must be verified before those files are committed here.

The project documentation should record:

- original author
- original project URL
- exact source revision or download
- original license
- files reused unchanged
- files modified for EnderArm

If the original license restricts commercial use, derivatives of those mechanical files must preserve the required terms.

## Firmware and software dependencies

Klipper and Moonraker remain separate upstream projects and are not redistributed as part of this repository. EnderArm contains only project-specific configuration, extensions, host software, and documentation needed to use them.

## Attribution rule

Do not remove author names, license notices, or attribution from third-party source files. Modified files should identify the upstream source and the nature of the EnderArm modification.

## BOM source

The EnderArm BOM is adapted from the ToolKnox BOM revision dated 2026-04-30. The adapted BOM preserves the upstream quantities as a baseline and documents which items are reused from the Ender donor, replaced by Ender-specific printed parts, retained, or removed.

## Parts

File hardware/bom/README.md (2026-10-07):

# Bill of Materials

EnderArm is designed to reuse as much of an Ender 3 or Ender 3 Pro as possible. The BOM is split into two parts:

1. hardware taken from the donor Ender
2. additional hardware required to complete the robotic arm

The mechanical arm is based on the ToolKnox robotic-arm design, but the EnderArm conversion replaces most of the original electronics, motors, power hardware, and several bearing/fastener parts with components already present on the Ender.

## From the Ender 3 / Ender 3 Pro

| Item | Qty | Use in EnderArm |
| --- | ---: | --- |
| Ender 3 or Ender 3 Pro | 1 | Donor machine |
| Original controller board | 1 | Klipper MCU and stepper-driver board |
| Original power supply | 1 | Powers the robot |
| Original stepper motors | 4 | Four powered robot axes |
| Original endstops | reuse | Homing / limit sensing |
| Original motor and endstop wiring | reuse | Robot wiring |
| Original Y-axis rail, carriage, belt, and extrusion | 1 set | Linear base axis |
| Original M5 screws, washers, T-nuts, and frame hardware | reuse | Mechanical assembly and converted pivots |
| Original 20T GT2 pulleys from X/Y motors | 2 | Main-arm and crank belt drives |

The donor printer replaces the separate Arduino Mega, RAMPS board, A4988 drivers, external NEMA17 motors, and separate power supply used by the upstream design.

## Additional hardware to buy

| Item | Qty | Specification | Use |
| --- | ---: | --- | --- |
| 624ZZ bearing | 6 | 4 mm bore × 13 mm OD × 5 mm wide | Use with [`624ZZ Flange Shim.stl`](../adapters/624ZZ%20Flange%20Shim.stl) |
| 686ZZ bearing | 12 | 6 mm bore × 13 mm OD × 5 mm wide | Use with [`686ZZ M5 Bearing Spacer.stl`](../adapters/686ZZ%20M5%20Bearing%20Spacer.stl) |
| Precision steel balls | enough to fill bearing shell | 6 mm diameter | Printed loose-ball bearing replacing the purchased thrust bearing |
| GT2 closed-loop timing belt | 3 | 200 mm circumference × 6 mm wide | Three rotary belt drives |
| GT2 20T pulley | 1 | 20 tooth, 5 mm bore, for 6 mm GT2 belt | Buy or print: [GT2 20T pulley STL](https://www.printables.com/model/730635-gt2-20t-pully-5mm-bore-optimized-for-fdm) |
| M2 × 10 mm button-head screw | 6 | M2 | Arm assembly |
| M3 × 6 mm button-head screw | 36 | M3 | Arm assembly |
| M4 × 10 mm button-head screw | 6 | M4 | Arm assembly |
| M4 × 16 mm button-head screw | 8 | M4 | Arm assembly |
| M4 × 20 mm button-head screw | 6 | M4 | Arm assembly |
| M2 nut | 6 | M2 | Arm assembly |
| M3 nut | 4 | M3 | Arm assembly |
| M4 lock nut | 14 | M4 | Arm assembly |

If matching M2/M3/M4 hardware is already available, those fasteners do not need to be purchased again.

## Print settings for conversion parts

Print the Ender-specific adapter parts with a **0.4 mm nozzle, 100% infill, and 100% model scale**. The fit adjustments in these parts were tuned around a dimensionally calibrated printer with good dimensional accuracy, such as a well-tuned Ender 3 Pro, Bambu Lab printer, or another reliable FDM printer.

## Printed conversion parts

These parts are printed rather than purchased:

| Part | Qty | Purpose |
| --- | ---: | --- |
| [`624ZZ Flange Shim.stl`](../adapters/624ZZ%20Flange%20Shim.stl) | 6 | Adds the required flange interface to standard 624ZZ bearings |
| [`6mm Ball Thrust Bearing Shell Top.stl`](../adapters/6mm%20Ball%20Thrust%20Bearing%20Shell%20Top.stl) | 1 | Upper half of the loose-ball bearing shell |
| [`6mm Ball Thrust Bearing Shell Bottom.stl`](../adapters/6mm%20Ball%20Thrust%20Bearing%20Shell%20Bottom.stl) | 1 | Lower half of the loose-ball bearing shell |
| [`686ZZ M5 Bearing Spacer.stl`](../adapters/686ZZ%20M5%20Bearing%20Spacer.stl) | 12 | Used with the 686ZZ bearings for the M5 pivot interface |
| [`Ender XY 20T Pulley Motor Spacer.stl`](../adapters/Ender%20XY%2020T%20Pulley%20Motor%20Spacer.stl) | 2 | Used with the donor X/Y motors and existing 20T pulleys |

### 624ZZ flange-shim conversion

Use standard 624ZZ bearings with the printed flange shim instead of purchasing F624ZZ flanged bearings.

### Bearing-shell conversion

The printed bearing shell uses loose 6 mm steel balls in place of the more expensive purchased thrust-bearing assembly.

### 686ZZ conversion

The upstream design uses flanged F686ZZ bearings and M6 pivot hardware. EnderArm instead uses standard 686ZZ bearings with a printed spacer. The spacer creates an M5-compatible center interface and flange-like retention so the original Ender hardware can be reused.

### Motor-spacer conversion

The Ender X/Y motors already have 20T GT2 pulleys installed. The motor spacers position those motors correctly in the arm so the pulleys can stay on the shafts.

## Estimated build cost

The cost below is a **budget estimate as of October 2026**. It uses representative U.S. online prices and the project's $30 used-Ender donor target. Shipping and sales tax are not included.

| Purchase | What it covers | Estimated cost |
| --- | --- | ---: |
| Used Ender 3 / Ender 3 Pro donor | Controller, PSU, 4 steppers, endstops, wiring, linear axis, frame hardware, two existing 20T pulleys | **$30.00** |
| 624ZZ bearings | 10-pack; 6 required | $10.99 |
| 686ZZ bearings | 20-pack; 12 required | $15.49 |
| 6 mm precision steel balls | 100-pack; enough for the printed bearing shell | $9.99 |
| 200 mm × 6 mm GT2 closed belts | 3 required | $1.50 |
| M2/M3/M4/M5 button-head fastener assortment | Covers the required M2/M3/M4 screws and standard nuts | $19.99 |
| M4 nylon lock nuts | 50-pack; 14 required | $8.99 |
| PETG filament allowance | One 1 kg spool for printed arm/conversion parts; actual consumption depends on slicer settings | $17.99 |
| GT2 20T pulley | Printed using the filament allowance | $0.00 |

### Reference total

```text
Additional materials:     $84.94
Used Ender donor:         $30.00
--------------------------------
Estimated robot total:   $114.94
```

**Budget target: about $115 for the complete robot hardware** when the donor Ender is obtained for about $30 and the additional 20T pulley is printed.

If the third 20T pulley is purchased instead of printed, a representative 5-pack is about $6.99, bringing the estimate to about **$121.93**.

### Host computer

The host is separate from the mechanical robot BOM. Use a Raspberry Pi or any other Debian/Linux computer with approximately **2 GB RAM and 2 GB available storage**.

If a compatible computer is already available, host cost is **$0 additional**.

The donor printer is the largest variable, so a more general estimate is:

```text
Robot total = donor Ender price + approximately $84.94
```

### Price references

Representative prices used for this estimate:

- 624ZZ 10-pack: $10.99
- 686ZZ 20-pack: $15.49
- 6 mm steel balls, 100-pack: $9.99
- 200 mm GT2 belt: $0.50 each
- M2-M5 button-head fastener assortment: $19.99
- M4 nylon lock nuts, 50-pack: $8.99
- 1 kg PETG filament allowance: $17.99

Prices change over time; the quantities and specifications in the BOM are the authoritative build requirements.

## Upstream reference

- [ToolKnox/Robotic-Arm-Arduino-project](https://github.com/ToolKnox/Robotic-Arm-Arduino-project)
- [Upstream BOM](https://github.com/ToolKnox/Robotic-Arm-Arduino-project/blob/main/BOM.pdf)
- [Mechanical model on Printables](https://www.printables.com/model/1439965-robotic-arm-arduino-project)

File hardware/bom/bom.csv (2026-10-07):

source | item | quantity | specification | use | estimated_purchase_cost_usd
Ender donor | Ender 3 or Ender 3 Pro | 1 |  | Donor machine | 30.00
Ender donor | Original controller board | 1 |  | Klipper MCU and stepper-driver board
Ender donor | Original power supply | 1 |  | Robot power
Ender donor | Original stepper motors | 4 |  | Four powered robot axes
Ender donor | Original endstops | reuse |  | Homing and limit sensing
Ender donor | Original wiring | reuse |  | Motor and endstop wiring
Ender donor | Original Y-axis rail carriage belt and extrusion | 1 set |  | Linear base axis
Ender donor | Original M5 screws washers T-nuts and frame hardware | reuse |  | Mechanical assembly and converted pivots
Ender donor | Original X/Y 20T GT2 pulleys | 2 | 20 tooth | Main-arm and crank drives
Buy | 624ZZ bearing | 6 | 4x13x5 mm | Use with hardware/adapters/624ZZ Flange Shim.stl | 10.99
Buy | 686ZZ bearing | 12 | 6x13x5 mm | Use with hardware/adapters/686ZZ M5 Bearing Spacer.stl | 15.49
Buy | 6 mm precision steel balls | enough to fill bearing shell | 6 mm diameter | Printed loose-ball bearing | 9.99
Buy | GT2 closed-loop timing belt | 3 | 200 mm circumference x 6 mm wide | Rotary belt drives | 1.50
Buy | GT2 20T pulley | 1 | 20 tooth 5 mm bore for 6 mm GT2 belt | Buy or print https://www.printables.com/model/730635-gt2-20t-pully-5mm-bore-optimized-for-fdm | 0.00
Buy | M2 x 10 mm button-head screw | 6 | M2 | Arm assembly
Buy | M3 x 6 mm button-head screw | 36 | M3 | Arm assembly
Buy | M4 x 10 mm button-head screw | 6 | M4 | Arm assembly
Buy | M4 x 16 mm button-head screw | 8 | M4 | Arm assembly
Buy | M4 x 20 mm button-head screw | 6 | M4 | Arm assembly
Buy | M2 nut | 6 | M2 | Arm assembly
Buy | M3 nut | 4 | M3 | Arm assembly
Buy | M4 lock nut | 14 | M4 | Arm assembly
Print | 624ZZ Flange Shim.stl | 6 |  | Adds flange interface to standard 624ZZ bearings
Print | 6mm Ball Thrust Bearing Shell Top.stl | 1 |  | Loose-ball bearing shell
Print | 6mm Ball Thrust Bearing Shell Bottom.stl | 1 |  | Loose-ball bearing shell
Print | 686ZZ M5 Bearing Spacer.stl | 12 |  | 686ZZ to M5 adapter with flange-like retention
Print | Ender XY 20T Pulley Motor Spacer.stl | 2 |  | Retains donor X/Y 20T pulleys

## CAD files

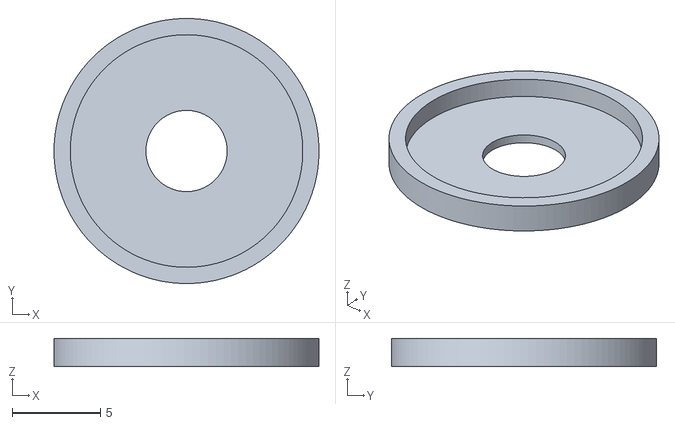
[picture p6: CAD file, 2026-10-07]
hardware/adapters/624ZZ Flange Shim.stl
15.0 x 15.0 x 1.60

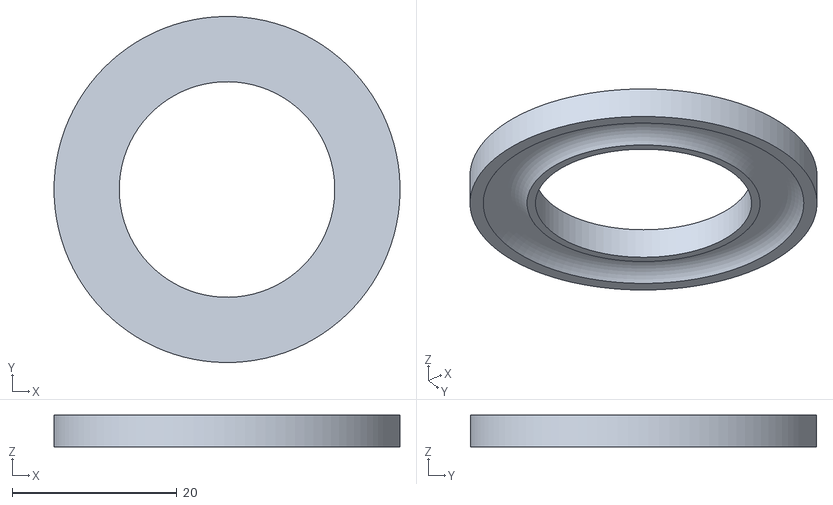
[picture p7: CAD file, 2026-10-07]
hardware/adapters/6mm Ball Thrust Bearing Shell Top.stl
42.0 x 42.0 x 3.85

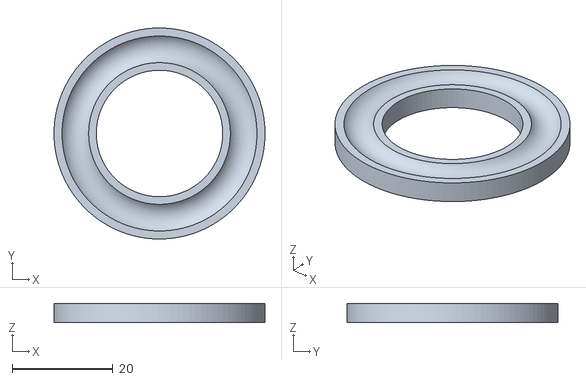
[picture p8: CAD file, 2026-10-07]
hardware/adapters/6mm Ball Thrust Bearing Shell Bottom.stl
42.0 x 42.0 x 3.85

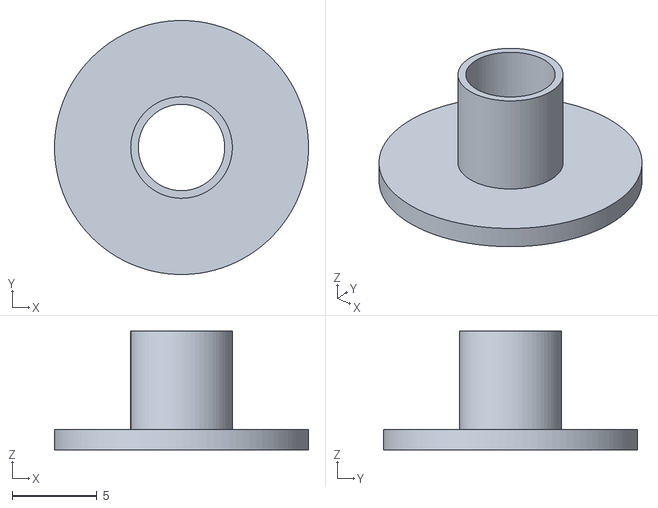
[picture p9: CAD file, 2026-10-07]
hardware/adapters/686ZZ M5 Bearing Spacer.stl
15.0 x 15.0 x 7.00

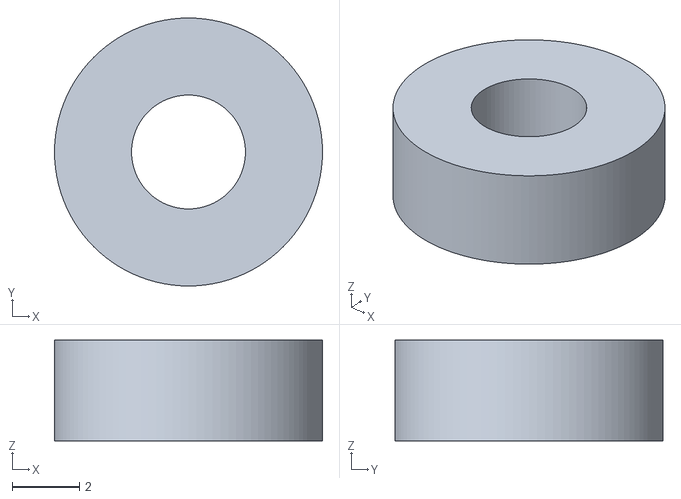
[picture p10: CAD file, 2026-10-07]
hardware/adapters/Ender XY 20T Pulley Motor Spacer.stl
8.00 x 8.00 x 3.00

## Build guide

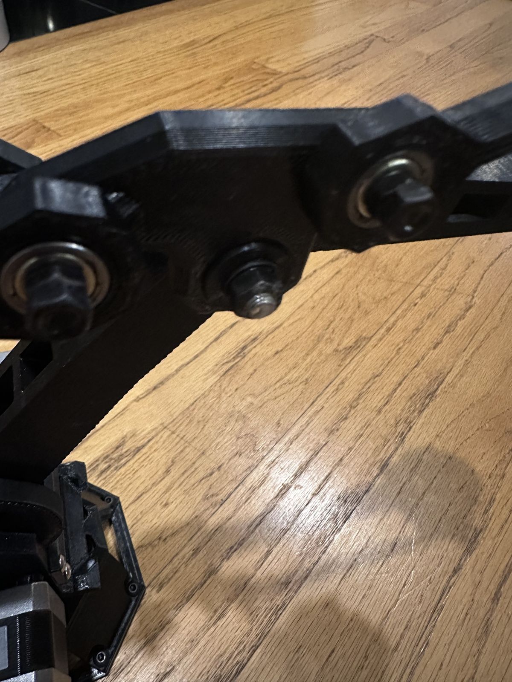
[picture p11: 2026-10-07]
docs/images/mechanical-assembly/linkage-bearing-detail.jpg

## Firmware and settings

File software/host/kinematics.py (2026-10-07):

"""Authoritative kinematics for the Alex Arm robotic arm.

This module owns the robot's geometric definitions.  Renderers, mappers, and
motor-control code must consume these definitions instead of inventing their
own coordinate systems.

SIDE-PLANE CONTRACT
-------------------
A = (X=0, Y=0, Z=0) is the common center of the two 90-tooth side pivots.
The side linkage moves in the Y-Z plane, therefore X=0 for every side pivot.
+Y points outward from the base toward the tool.
+Z points upward.
qX is the absolute angle of link A-C (120 mm).
qY is the absolute angle of link A-B (40 mm).
qX=qY=0 degrees means the respective link points along +Z.
Positive q rotates from +Z toward +Y.

Physical homing does NOT redefine geometric zero.  Measured home/index
positions are converted to qX/qY with explicit calibration offsets and signs.

The long-term control path is:
Cartesian target -> inverse kinematics -> qX/qY -> calibrated 90T angles
-> motor shaft angles/microsteps -> hardware.
All lengths are millimetres and all public angles are degrees.
"""

from __future__ import annotations

from dataclasses import dataclass
from math import acos, atan2, cos, degrees, hypot, radians, sin


# --- Authoritative side-plane coordinate contract ---
# A is the common side-pivot origin.  All side-linkage pivots have X = 0.
SIDE_ORIGIN = (0.0, 0.0, 0.0)  # (X, Y, Z) mm
SIDE_PLANE = "YZ"
ANGLE_ZERO_AXIS = "+Z"
ANGLE_POSITIVE_TOWARD = "+Y"

LOWER_LINK_MM = 120.0       # A-C, the qX driven arm
CRANK_LINK_MM = 40.0        # A-B, the qY driven crank
UPPER_LINK_MM = 120.0
TOOL_RADIAL_OFFSET_MM = 54.0

# --- Motor / gearbox definition ---
# 20T motor pulley -> 90T driven/output pulley.
MOTOR_PULLEY_TEETH = 20.0
DRIVEN_PULLEY_TEETH = 90.0
OUTPUT_DEGREES_PER_MOTOR_DEGREE = MOTOR_PULLEY_TEETH / DRIVEN_PULLEY_TEETH
MICROSTEPS_PER_MOTOR_REVOLUTION = 16.0 * 200.0

# --- Measured physical HOME references ---
# Angle convention is now visually grounded:
#   0 deg   = straight up along +Z
#   +90 deg = horizontal toward +Y
#   -90 deg = horizontal toward -Y
# Therefore A-C = -70 deg is a strong backward tilt: only 20 deg above -Y.
#
# A-C is the directly measured main-arm home bearing.
HOME_AC_DEGREES = -70.0
#
# Current Assembly-1 home seed for the driven A-B crank.  Keep this separate
# from follower-link observations: B-F is NOT a motor coordinate.  Refine this
# value only from the physical A-B/home calibration.
HOME_QY_DEGREES = -104.0
#
# Independently observed home tool-tip reference from the previous mapper.
# This is a validation target; it is not used to redefine the measured angles.
HOME_TOOL_REFERENCE_X_MM = -3.0
HOME_TOOL_REFERENCE_Y_MM = 54.0
HOME_TOOL_REFERENCE_Z_MM = 130.0

# The closed four-bar has two mathematical F intersections.
# Assembly 1 = first returned circle intersection (f1): the physical
# upright/outward inverted-V branch. Assembly 2 = the mirror branch.
PHYSICAL_ASSEMBLY = 1

# User-measured, assembled-safe side-axis output positions.  The first value is
# X (the main 120 mm A-C arm); the second is Y (the 40 mm A-B crank).  These
# are angles of the 90-tooth driven gears, not motor-shaft angles.
TESTED_SIDE_OUTPUT_ANGLE_PAIRS_DEGREES: tuple[tuple[float, float], ...] = (
    (36.67, 14.44), (36.22, 30.44), (27.78, 30.44), (29.56, 8.89),
    (16.22, 17.78), (11.78, 13.33), (11.78, 13.33), (6.44, 8.89),
    (2.89, 5.78), (0.00, 2.22), (23.11, 2.22), (32.89, 13.33),
    (34.22, 13.33), (35.11, 13.78), (36.44, 14.67), (19.56, 20.89),
    (24.44, 26.22), (32.89, 32.44), (36.89, 31.56), (41.78, 24.89),
    (41.78, 20.00), (39.56, 17.33), (0.00, 0.00), (22.22, 0.00),
    (33.33, 11.11), (40.44, 17.78), (40.89, 30.67),
)


@dataclass(frozen=True)
class Point:
    """A Cartesian point in millimetres."""

    x: float
    y: float
    z: float


@dataclass(frozen=True)
class ArmPoints:
    """Centers of the kinematic pivots and the tool center point."""

    shoulder: Point
    elbow: Point
    wrist: Point
    tool_center: Point


@dataclass(frozen=True)
class JointAngles:
    """Side-plane output angles in the reference firmware convention."""

    base_degrees: float
    lower_degrees: float
    upper_degrees: float


@dataclass(frozen=True)
class LinkageDimensions:
    """Dimensions for the A-I side linkage drawn in the project sketch.

    The fixed ``A-G`` vector is chosen so A-G-E-C is a parallelogram and the
    D-E triplate edge is level in the side view. Replace its direction only
    after checking the physical assembly's neutral pose.
    """

    crank_ab_mm: float = 40.0
    lower_ac_mm: float = 120.0
    lower_blue_bf_mm: float = 120.0
    red_tail_cf_mm: float = 40.0
    upper_ch_mm: float = 120.0
    triplate_cd_mm: float = 25.0
    triplate_ce_mm: float = 32.0
    triplate_de_mm: float = 45.0
    green_ge_mm: float = 120.0
    upper_blue_di_mm: float = 120.0
    wrist_hi_mm: float = 25.0
    tool_nub_ht_mm: float = 27.0
    # A-G = C-E = 32 mm. This vector also sets the constant plate orientation.
    ground_g_y_mm: float = -26.933333333333334
    ground_g_z_mm: float = 17.27991769527724


@dataclass(frozen=True)
class LinkagePoints:
    """All labelled side-plane pivots in the dimension-driven A-I model."""

    a: Point
    b: Point
    c: Point
    d: Point
    e: Point
    f: Point
    g: Point
    h: Point
    i: Point
    tool: Point


@dataclass(frozen=True)
class MemberAngles:
    """Absolute side-plane member angles, measured from +Z toward +Y.

    ac_degrees is the main A-C driven arm and is exactly qX.
    ab_degrees is the short A-B crank and is exactly qY.
    bf_degrees is the blue B-F connecting link.
    fch_degrees is the red F-C-H member; F, C and H are collinear.
    """

    ac_degrees: float
    ab_degrees: float
    bf_degrees: float
    fch_degrees: float
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

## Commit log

2026-10-07 Correct bearing hardware and conversion adapters
2026-10-07 Document bearing shells and Ender conversion spacers
2026-10-07 Correct bearing photo documentation
2026-10-07 Add initial EnderArm bill of materials
2026-10-07 Document Ender-specific printed adapters
2026-10-07 Adapt upstream ToolKnox BOM for EnderArm
2026-10-07 Add machine-readable EnderArm BOM
    [bom.csv]
2026-10-07 Attribute upstream ToolKnox BOM and mechanical design
2026-10-07 Link full adapted BOM from project README
2026-10-07 Document EnderArm kinematics and Cartesian conversion math
2026-10-07 Link kinematics math documentation
2026-10-07 Simplify BOM into donor and additional hardware
2026-10-07 Simplify BOM CSV into donor and buy sections
    [bom.csv]
2026-10-07 Link BOM parts to spacer STL and printable pulley
2026-10-07 Link printable pulley and bearing spacer in BOM CSV
    [bom.csv]
2026-10-07 Replace F624ZZ with standard 624ZZ and printed flange shim
2026-10-07 Use standard 624ZZ bearings with printed flange shims
    [bom.csv]
2026-10-07 Rename adapter STLs with specific functional names
    [686ZZ M5 Bearing Spacer.stl, 6mm Ball Thrust Bearing Shell Bottom.stl, 6mm Ball Thrust Bearing Shell Top.stl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]
2026-10-07 Document print settings and Ender mechanical assembly
2026-10-07 Add adapter print settings and fit guidance
2026-10-07 Add conversion-part print settings and repair STL links
2026-10-07 Add estimated purchase costs to BOM CSV
    [bom.csv]
2026-10-07 Add exact EnderArm kinematics diagram
2026-10-07 Add reproducible kinematics geometry script
2026-10-07 Add exact kinematics joint diagram
2026-10-07 Reference upstream arm design and assembly instructions
2026-10-07 Remove dedicated Wyse requirement from BOM
2026-10-07 Make kinematics diagram generator fully reproducible
2026-10-07 Replace 624ZZ flange shim with revised STL
    [624ZZ Flange Shim.stl]
2026-10-07 Document beer-pouring use case and fourth endstop
2026-10-07 Document fourth endstop thermistor-input conversion
2026-10-07 Add fourth-endstop Klipper configuration
2026-10-07 Fix kinematics diagram linkage visibility
2026-10-07 Make kinematics generator match exact linkage drawing
2026-10-07 Add Klipper arm control module
2026-10-07 Add exact EnderArm kinematics and inverse solver
2026-10-07 Add EnderArm kinematics regression tests
2026-10-07 Add Klipper web UI and motion controller
